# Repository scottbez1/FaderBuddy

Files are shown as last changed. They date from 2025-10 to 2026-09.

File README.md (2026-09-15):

# FaderBuddy

The FaderBuddy is a modular control board for 60mm motorized linear potentiometers, making it simple to add
one (or many) to a project with just 2 pins for I2C, plus power!

DSC_8984 Large

The control board allows you to **read** the fader position, **move** the fader to a specified position, and it can even provide **haptic feedback** and virtual detents (kind of like a linear version of my [SmartKnob](https://github.com/scottbez1/smartknob) project), all easily controlled over an I2C bus from a host controller like an ESP32.

An [ESPHome component](ABOUT_ESPHOME_INTEGRATION.md) allows
FaderBuddy assemblies to be seamlessly integrated into Home Assistant with just a few lines of yaml! 

The onboard ATtiny1616 microcontroller handles all the real-time logic (closed-loop motor control and capacitive
touch handling) and provides a simple I2C bus interface - no need to wire a motor driver/H-bridge or implement a PID control loop for each motor fader yourself.

Multiple FaderBuddy boards can be wired together and share just two I2C pins. With right-angle pin headers, you can plug adjacent FaderBuddy boards into
each other without any wires for an easy plug-and-play expandable system (supports 18mm or 19mm spacing between faders).
STEMMA QT/QWIIC-compatible connectors make it easy to hook FaderBuddy boards to the rest of your design (see [wiring diagrams](#wiring-overview) below for examples).

<!--
<img alt="motor fader demo tiny" height="427" src="https://github.com/user-attachments/assets/fc8dd191-fca0-4ac6-80d8-bb88dc9d0a7a" />
-->
<p align="center">
FaderBuddySimpleTopDown
</p>

The [FaderBuddy community Discord server](https://discord.gg/xZXQAp5cue) is the best place to keep up with the latest changes or ask questions about the project!

<p align="center">
<a href="https://www.youtube.com/shorts/l-DIM_kQ8EY" target="_blank">
thumbnailPlayButton
</a>
</p>

Learn more about the project and how to build your own below, or purchase a FaderBuddy from the [Bezek Labs Etsy store](https://bezeklabs.etsy.com/listing/4506790932/) (US-only).

---

Want to help support development or just say "thanks"? Consider a one-time or monthly sponsorship:

| [:heart: Sponsor scottbez1 on GitHub](https://github.com/sponsors/scottbez1) |
|---|

**Using this project in a commercial setting or for paid client work?** Go right ahead - it's open source (just make sure to follow the terms of the Apache License including attribution)! I would, however, ask that you consider [sponsoring the project](https://github.com/sponsors/scottbez1). Sponsorships allow me to pay for prototypes and development tools that make this project possible. Unlike pure software projects, every iteration has real hardware costs; sponsorships allow me to keep iterating and improving this and other projects faster. Thank you!

---

## ESPHome Integration

The FaderBuddy integrates seamlessly with [ESPHome](https://esphome.io/) for Home Assistant automation. The custom component provides:
- Bidirectional (input & output) position sync with Home Assistant entities
- Layer-aware automation triggers (manual_move, touch_change, double_tap)
- Per-layer haptic configuration
- Multiple faders on a single ESP32 via I2C

A simple example looks like:
```yaml
external_components:
  - source: github://scottbez1/FaderBuddy

fader_buddy:
  - id: my_fader
    on_manual_move:
      then:
        - lambda: |-
            ESP_LOGD("fader", "Fader moved to %d on layer %d", x, layer);
```

and to move the fader from a lambda:
```cpp
id(my_fader).remote_move_to(position, layer);

// optionally cap the speed - 0-255, where 255 is full speed
id(my_fader).remote_move_to(position, layer, 128);
```

That's pretty much all there is to it!

See [ABOUT_ESPHOME_INTEGRATION.md](ABOUT_ESPHOME_INTEGRATION.md) for setup instructions and many more examples.

## Getting Started
What you need:
- **60mm motorized fader**: Behringer MF60T faders (sold in 5-packs as replacement parts) from music/AV retailers like [Sweetwater](https://www.sweetwater.com/store/detail/MOTORFADER--behringer-mf60t-motorized-faders-set-of-5-for-motor-controllers) or [Amazon](https://www.amazon.com/Behringer-MOTOR-High-Performance-Faders-Keyboards/dp/B01DT827IC) - these appear to be manufactured by Soundwell
- **FaderBuddy PCB**: Available [pre-assembled from Bezek Labs](https://bezeklabs.etsy.com/listing/4506790932) in the US (purchasing there directly supports this project), or use the design files fabricate and assemble your own PCBs via JLCPCB. See [ABOUT_PCB_FABRICATION.md](ABOUT_PCB_FABRICATION.md) for details.
- **ESP32**: Any ESPHome-compatible ESP32 board with 2 free GPIO pins for I2C.

> [!NOTE]
> If fabricating your own boards via JLCPCB, you'll also need to flash the firmware before use. See [ABOUT_UPDATING_FIRMWARE.md](ABOUT_UPDATING_FIRMWARE.md) for instructions.

## Wiring Overview
| Pin | Details |
| --- | --- |
| Vmot | Motor power - 5v recommended |
| Vio | Microcontroller IO power - 3.3v or 5v. This must match the voltage for the SDA/SCL I2C bus! |
| GND | Ground reference |
| SDA | I2C data. FaderBuddy includes a pull-up resistor |
| SCL | I2C clock. FaderBuddy includes a pull-up resistor |

### 3.3v MCU direct wired, direct chaining
Most common wiring for 3.3v microcontrollers like ESP32: 5 wires from host to FaderBuddy. 5v powers the motor and 3.3v powers the logic.

FaderBuddy wiring

| HOST | FaderBuddy |
| --- | --- |
| 5v  | Vmot |
| 3.3v | Vio |
| GND | GND |
| SDA | SDA |
| SCL | SCL |

<br clear="right" />

### 3.3v MCU STEMMA QT
For a microcontroller with a STEMMA QT connector, the FaderBuddy requires an additional 5v wire to power the motor. Additional faders can be chained directly using the pin headers with no extra wires.

FaderBuddy wiring(2)

| HOST | FaderBuddy |
| --- | --- |
| STEMMA QT | STEMMA QT |
| 5v  | Vmot |

<br clear="right" />
<br />
FaderBuddy wiring(1)
Alternatively, FaderBuddy boards can be chained using STEMMA QT cables, but an additional 5v wire is also required between each board in that case.
<br clear="right" />

### 5v STEMMA QT
If you have a device that has 5v IO and a 5v STEMMA QT connector (e.g. MCP2221 with the solder jumper bridged to set 5v IO)

FaderBuddy wiring(4)

| HOST | FaderBuddy |
| --- | --- |
| STEMMA QT | STEMMA QT |

You must also bridge the V<sub>MOT</sub> ↔ V<sub>IO</sub> solder bridge on _each_ FaderBuddy so that the 5v IO can be shared with the motor driver.

_Be careful when using these solder bridges - if you leave this connection bridged and then later use the FaderBuddy in a 3.3v IO setting, the bridge will connect the 5v V<sub>MOT</sub> supply to your host 3.3v IO supply which may damage other connected devices!_

<br clear="right" />
(Board images attribution: ESP32-C3 supermini image from StudioPieters, MIT Licensed; Adafruit Qt Py and Adafruit MCP2221 images from Adafruit, Creative Commons Attribution/Share-Alike)

### Setting I2C Address
By default the FaderBuddy will use I2C address `0x20`.

When connecting more than one FaderBuddy to the same I2C bus, or if there's already another device on your bus with that address, the FaderBuddy PCB has 3 solder jumper pads allowing you to change the I2C address by bridging those pads.

| Address | A2 | A1 | A0 |
| --- | ----- | ----- | ----- |
| `0x20`  | `[ ]` | `[ ]` | `[ ]` |
| `0x21`  | `[ ]` | `[ ]` | `[█]` |
| `0x22`  | `[ ]` | `[█]` | `[ ]` |
| `0x23`  | `[ ]` | `[█]` | `[█]` |
| `0x24`  | `[█]` | `[ ]` | `[ ]` |
| `0x25`  | `[█]` | `[ ]` | `[█]` |
| `0x26`  | `[█]` | `[█]` | `[ ]` |
| `0x27`  | `[█]` | `[█]` | `[█]` |

## About the Board Design
The most plug-and-play option (if you're in the US) is to buy the FaderBuddy PCBs [pre-assembled from the Bezek Labs store](https://bezeklabs.etsy.com/listing/4506790932), which come with firmware already flashed, the hardware tested, and it helps support this project and future development!

To fabricate or assemble the PCBs yourself, see [ABOUT_PCB_FABRICATION.md](ABOUT_PCB_FABRICATION.md) for more info on ordering.

**Hardware details:**
- ATtiny1616 microcontroller with UPDI programming interface
- Supports 3.3v or 5v logic (with 3.3v logic, 5v is still required for powering the motor; with 5v logic Vio and Vmot can be combined for only 4 wires)
- DRV8837 motor driver, with potentiometer position feedback for closed-loop control
- JST connectors for I2C (QWIIC/STEMMA QT-compatible), or 0.1" pin headers for directly chaining adjacent boards
- Capacitive touch sensing for fader touch detection
- Power and debug status LEDs
- Compact PCB design optimized for JLCPCB assembly

<a href="https://motorfader-artifacts.s3.amazonaws.com/master/electronics/fader_buddy_main-schematic.pdf">
    
</a>
<br />
<a href="https://motorfader-artifacts.s3.amazonaws.com/master/electronics/fader_buddy_main-3D_top.png">
    
</a>
<a href="https://motorfader-artifacts.s3.amazonaws.com/master/electronics/fader_buddy_main-3D_bottom.png">
    
</a>

## Touch-compatible Fader Knobs/Caps
You don't _need_ touch capable fader caps - the FaderBuddy will work fine without them - but touch detection allows the FaderBuddy to cancel a motor movement if it detects a touch along the way, preventing the fader from "fighting" against the user. It also allows the FaderBuddy to detect if a user is touching the fader even if they aren't actively moving, and allows you to support a double-tap action on the fader if you'd like.

It's unfortunately nearly impossible to find off-the-shelf mass produced touch-capable fader knobs. Although the Soundwell/Behringer faders use a relatively standard 8mm x 1.2mm fader stem, pretty much all commercially available fader caps are non-conductive plastic and thus do not support touch detection, or are only available as expensive individual replacement parts (oftentimes in used condition).

However, I've found that you can 3D print touch-capable fader caps using conductive PLA filament. Although conductive PLA is generally very high resistance, this is actually a great property for making a touch detection surface.

If you don't want to print your own, you can purchase these 2-color single-piece conductive fader caps in the [Bezek Labs store](https://bezeklabs.etsy.com/listing/4501804398).

<a href="https://bezeklabs.etsy.com/listing/4501804398">
Screenshot 2026-05-15 at 9 19 08 AM
Screenshot 2026-05-15 at 9 19 33 AM
<br />
Screenshot 2026-05-15 at 9 19 56 AM
</a>

## Firmware, I2C interface, and Layers
The FaderBuddy firmware internally handles the closed loop motor control, presenting a [simple I2C interface](firmware/src/shared/i2c_data.h) that can be used to read the position and status of the board, command a movement to a position, and configure haptic feedback. This I2C interface is wrapped up in the ESPHome component, making it a great reference for how to interact with the protocol if you'd like to connect your FaderBuddy to something besides an ESP32 with ESPHome.

- Programmable haptic-feedback modes:
  - Smooth operation (no detents)
  - Magnetic endpoints (snap to 0% and 100%)
  - Configurable detents (1-15 positions)

Configuration of a FaderBuddy supports up to 8 virtual "layers", which allow a single fader to be used for multiple purposes (e.g. controlling lamp brightness and fan speed), with the host controller able
to send a single command to switch to a different layer. Switching layers restores the previous
fader position for that layer, and will apply that layer's haptic configuration.

See [ABOUT_LAYERS.md](ABOUT_LAYERS.md) for more about layers and the I2C protocol.

## Additional Documentation
This README covers the basics, but there are a number of additional pages with more detailed documentation:

- **[ABOUT_ESPHOME_INTEGRATION.md](ABOUT_ESPHOME_INTEGRATION.md)** - ESPHome setup and API reference
- **[ABOUT_LAYERS.md](ABOUT_LAYERS.md)** - Layer architecture and implementation details
- **[ABOUT_MF60T_LOW_PROFILE_MOD.md](ABOUT_MF60T_LOW_PROFILE_MOD.md)** - Optional instructions for modifying the MF60T faders so they can fit in smaller areas
- **[ABOUT_PCB_FABRICATION.md](ABOUT_PCB_FABRICATION.md)** - How to order and assemble your own FaderBuddy boards directly
- **[ABOUT_UPDATING_FIRMWARE.md](ABOUT_UPDATING_FIRMWARE.md)** - How to upload firmware to the FaderBuddy microcontroller using UPDI
- **[ABOUT_I2C_BOOTLOADER.md](ABOUT_I2C_BOOTLOADER.md)** - How firmware updates work over I2C (no UPDI programmer), via the custom bootloader in the ATtiny1616 boot section

### Project Structure
```
FaderBuddy/
├── electronics/         # KiCad PCB design files
├── firmware/            # ATtiny1616 firmware source (PlatformIO)
├── esphome/             # ESPHome custom component
│   ├── components/      # Component source code
│   └── examples/        # Example configurations
├── software/            # Software tools and demos
│   └── mcp2221-webhid/  # WebHID browser demo tool
├── production_tools/    # ESP32-based production test fixture
└── ci/                  # CI scripts for PCB export
```

## Production Testing

The `production_tools/programAndTest` directory contains unsupported (source-provided) code for programming and quality control of motor fader boards during production.

## License

FaderBuddy is released under the [Apache 2.0 License](LICENSE.txt).

In plain terms: you're free to use, modify, and distribute this project — including in commercial products — as long as you include the license with attribution to this project and indicate any changes you made. You don't have to share your modifications, but you can't claim the original work is yours or use the project name/branding to endorse your product.

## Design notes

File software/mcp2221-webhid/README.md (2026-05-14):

# FaderBuddy WebHID Demo

Web-based interface for controlling FaderBuddy devices via MCP2221 USB-to-I2C bridge using WebHID.

## Setup

1. Install dependencies:
```bash
npm install
```

2. Build the bundle:
```bash
npm run build
```

3. Open `index.html` in a WebHID-compatible browser (Chrome, Edge, or other Chromium-based browsers)

## Development

To automatically rebuild on file changes:
```bash
npm run watch
```

## Usage

1. Connect your MCP2221 USB device to your computer
2. Ensure the FaderBuddy is connected to the MCP2221's I2C pins
3. Open `index.html` in your browser
4. Click "Connect MCP2221" and select the device
5. Verify the I2C address matches your fader (default: 0x20)
6. Control and monitor your FaderBuddy in real-time

## Features

- Real-time position monitoring (10Hz polling)
- Bidirectional control (set target position)
- Mode state visualization
- Touch detection monitoring
- Touch diagnostics (raw/delta/reference values)
- Error handling and recovery
- Self-calibration trigger

## Requirements

- WebHID-compatible browser (Chrome 89+, Edge 89+)
- MCP2221/MCP2221A USB-to-I2C bridge
- FaderBuddy hardware with I2C interface

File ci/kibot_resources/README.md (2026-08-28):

# KiBot resources

KiBot's `resources_dir` global option (set in the `.kibot.yml` files) points here.
At startup KiBot globs `<resources_dir>/fonts/*.ttf` and installs what it finds
into `~/.fonts` *inside its Docker container* — that's the only way KiCad running
under the KiBot Actions can see a custom font, since it can't read the fonts that
`ci/electronics/dependencies.sh` installs on the runner itself.

The glob is flat and non-recursive, so the font has to sit directly in `fonts/`.
`fonts/Righteous-Regular.ttf` is therefore a symlink to the real file in
`ci/fonts/Righteous/`, which is where the runner-side tooling reads it from.

Symptom if this breaks: silkscreen text that uses the Righteous outline font
renders in KiCad's default stroke font in the 3D renders, while the gerbers (which
are plotted on the runner, not in the container) still look correct.

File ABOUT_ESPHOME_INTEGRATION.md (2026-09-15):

# FaderBuddy ESPHome Integration

This guide shows you how to use the FaderBuddy with ESPHome to create smart motorized controls for Home Assistant or other home automation systems.

## Hardware Setup

### Wiring

Connect your FaderBuddy board(s) to your ESP32 via I2C:

- **SDA** → ESP32 GPIO pin (e.g., GPIO8)
- **SCL** → ESP32 GPIO pin (e.g., GPIO9)
- **GND** → ESP32 GND
- **Vio** → 3.3V power supply
- **Vmot** → 5V power supply

**I2C Addressing**: Each FaderBuddy has a configurable I2C address (default 0x20, configurable via hardware jumpers to 0x20-0x27). When using multiple faders on the same I2C bus, ensure each has a unique address.

### I2C Bus Configuration

In your ESPHome YAML, configure the I2C bus:

```yaml
i2c:
  sda: GPIO8
  scl: GPIO9
  scan: true  # Optional: helps verify faders are detected
```

## Adding the Component

### External Component Reference

Add the fader_buddy component to your ESPHome configuration using the GitHub repository:

```yaml
external_components:
  - source:
      type: git
      url: https://github.com/scottbez1/FaderBuddy.git
      ref: master  # or specify a specific tag/branch
    components: [fader_buddy]
```

## Basic Configuration

### Single Fader Setup

Here's a minimal configuration for one FaderBuddy:

```yaml
fader_buddy:
  - id: my_fader
    address: 0x20          # I2C address (default 0x20)
    update_interval: 10ms  # How often to poll the fader
```

### Multiple Faders

To use multiple faders, add multiple entries with unique IDs and addresses:

```yaml
fader_buddy:
  - id: fader_1
    address: 0x20
    update_interval: 10ms

  - id: fader_2
    address: 0x21
    update_interval: 10ms

  - id: fader_3
    address: 0x22
    update_interval: 10ms
```

## Complete Example: Light Brightness Control

This example shows bidirectional control - a single fader controlling a Home Assistant light's brightness and responding to remote changes to that light's brightness:

```yaml
fader_buddy:
  - id: brightness_fader
    address: 0x20
    update_interval: 10ms
    layer_haptics:
      - layer: 0
        mode: smooth
        default_speed: 120  # move deliberately rather than instantly

    # User moves fader → update light brightness
    on_manual_move:
      then:
        - homeassistant.action:
            action: light.turn_on
            data:
              entity_id: light.living_room
              brightness: !lambda 'return x;'
              transition: "0"

# Light brightness changes in Home Assistant → move fader
sensor:
  - platform: homeassistant
    id: living_room_brightness
    entity_id: light.living_room
    attribute: brightness
    internal: true
    on_value:
      then:
        - lambda: |-
            id(brightness_fader).remote_move_to(isnan(x) ? 0 : x);
```

For additional complete working examples, see the `esphome/examples/` directory:

- **multi-fader-display.yaml** - Three faders with an LVGL display, showing haptic configuration, layer setup, and Home Assistant integration

## Configuration Options

### Component Configuration

- **id** (required): Unique identifier for this fader instance, used to reference it in automations and lambdas
- **address** (optional, default: `0x20`): I2C address of the fader (0x20-0x27)
- **update_interval** (optional, default: `50ms`): How often to poll the fader for state updates
- **invert** (optional, default: `false`): Reverse the fader direction (position 0 becomes 255, and vice versa)
- **layer_haptics** (optional): List of haptic configurations for specific layers. See `ABOUT_LAYERS.md` for more details on layers
  - **layer** (required): Layer index (0-7) for this list item
  - **mode** (required): Haptic mode - one of:
    - `smooth`: No haptic feedback, completely smooth movement
    - `smooth_with_magnets`: Smooth with magnetic endpoints that pull the fader to min/max
    - `detents`: Creates distinct "notches" along the fader's travel (requires `detent_count`)
  - **detent_count** (optional, default: `0`): Number of detents (1-15, for detents mode only)
  - **detent_strength** (optional, default: `0`): Detent force feedback strength (0-7, for detents mode only)
  - **default_speed** (optional, default: `255`, requires fader firmware 1.1+): Move speed for this layer, 0-255, used by `fader_buddy.remote_move_to` and by lambda calls to `remote_move_to()` that don't pass a speed of their own. `255` is full speed; see the `speed` parameter of `fader_buddy.remote_move_to` below. This one is tracked in ESPHome rather than on the fader — the component looks up the active layer's value and sends it with each move — so changing it costs no extra I2C traffic.
  - **value_change_min_interval** (optional, default: `0ms`): Rate limiting for `on_manual_move` trigger on this layer. Useful to reduce traffic when controlling networked devices like zigbee lights. Set to `0ms` for no rate limiting. Keep as low as possible.
- **firmware** (optional): Released fader firmware to package for I2C updates. See [Firmware updates](#firmware-updates) below. Mutually exclusive with `firmware_image`.
- **firmware_image** (optional): Path to a locally built application image, for iterating on an unreleased build. Mutually exclusive with `firmware`.

### Triggers

The component provides four triggers that fire in response to fader state changes:

#### on_manual_move

Fires when the user moves the fader. Only fires during `MODE_INPUT_ACTIVE` or `MODE_INPUT_IDLE` (i.e. not during remote motor movements). Respects `value_change_min_interval` rate limiting configured in `layer_haptics`. Provides the current position (0-255) and active layer index.

```yaml
fader_buddy:
  - id: my_fader
    on_manual_move:
      then:
        - lambda: |-
            // x = position (0-255)
            // layer = active layer (0-7)
            ESP_LOGD("fader", "Fader moved to %d on layer %d", x, layer);
```

#### on_touch_change

Fires when the user touches or releases the fader. Provides touch state (true/false) and active layer index.

```yaml
fader_buddy:
  - id: my_fader
    on_touch_change:
      then:
        - lambda: |-
            // x = touch state (true/false)
            // layer = active layer (0-7)
            ESP_LOGD("fader", "Touch: %s (on layer %d)", x ? "pressed" : "released", layer);
```

#### on_double_tap

Fires when the user double-taps the fader. Provides the active layer index.

```yaml
fader_buddy:
  - id: my_fader
    on_double_tap:
      then:
        - lambda: |-
            // layer = active layer (0-7)
            ESP_LOGD("fader", "Double tap on layer %d", layer);
```

#### on_raw_position_update

_Not recommended for general use!_ Fires on every position change detected by the hardware, regardless of the current mode and without any rate limiting. This includes position changes during remote motor movements (`MODE_REMOTE_MOVEMENT_IN_PROGRESS`), not just user-initiated moves. Provides the current position (0-255, after applying `invert`) and active layer index.

For most use cases, prefer `on_manual_move`. Use `on_raw_position_update` only when you specifically need to track the fader's physical position at all times — for example, to update a display that should reflect position even while the motor is actively moving.

```yaml
fader_buddy:
  - id: my_fader
    on_raw_position_update:
      then:
        - lambda: |-
            // x = position (0-255)
            // layer = active layer (0-7)
            ESP_LOGD("fader", "Raw position: %d on layer %d", x, layer);
```
## Actions

### fader_buddy.remote_move_to

Command the fader to move to a specific position.

```yaml
# Example: Move fader to position 128
- fader_buddy.remote_move_to:
    id: my_fader
    position: 128
    layer: 0  # Optional, defaults to layer 0

# Example: move gently rather than at full speed
- fader_buddy.remote_move_to:
    id: my_fader
    position: 200
    speed: 80
```

**Position:** 0-255 (0 = bottom, 255 = top, unless inverted)

**Layer:** Optional layer index (0-7). If the specified layer is not currently active, the position is stored and will be restored when that layer becomes active.

**speed:** Optional. How fast to move, as a unitless **0-255** value: `255` is full speed, `0` is the slowest the fader moves smoothly. Omit it to use the layer's `default_speed`.

Requires fader firmware **1.1 or newer**. On older firmware the component logs a warning once and moves at full speed instead; it checks the firmware version at startup, so a `default_speed` that cannot be honoured is reported then rather than on the first move.

The scale is linear in velocity, and both ends are usable — `0` is the slowest speed the mechanism sustains without creeping in stick-slip steps (roughly 700ms for full travel), and `255` removes the limit entirely. There is nothing outside the range worth reaching for.

This caps the fader's speed rather than scheduling the move, so a shorter move takes proportionally less time — at a given speed, a half-scale move takes about half as long as a full-scale one. Slowing moves down is mostly useful when several faders move at once, or when you want motion to read as deliberate rather than instant.

Treat it as a limit rather than a precise speed. It is realised through a friction-dependent mechanism, so actual velocity lands within about 15% of nominal, with around 7% difference between moving up and moving down.

Moving a layer that is not currently active also stores the speed, so it applies when that layer is restored later.

### fader_buddy.set_active_layer

Switch to a different layer (0-7). The fader will automatically move to that layer's last position.

```yaml
# Example: Button to switch to layer 1
binary_sensor:
  - platform: gpio
    pin: GPIO4
    on_press:
      - fader_buddy.set_active_layer:
          id: my_fader
          layer: 1
```

### fader_buddy.set_layer_haptic_config

Dynamically change the haptic configuration for a layer.

```yaml
# Example: Set layer 2 to detents mode with 10 detents
- fader_buddy.set_layer_haptic_config:
    id: my_fader
    layer: 2
    mode: detents
    detent_count: 10
    detent_strength: 5
```

### fader_buddy.run_self_calibration

Trigger the fader's self-calibration routine. The fader will automatically move to both endpoints to calibrate its potentiometer range.

```yaml
# Example: Calibration button
button:
  - platform: template
    name: "Calibrate Fader"
    on_press:
      - fader_buddy.run_self_calibration:
          id: my_fader
```

## Firmware updates

The fader's own ATtiny1616 firmware can be updated over I2C through its bootloader,
without a UPDI programmer. The image is embedded in the ESP32 build and streamed to
the fader when you call `fader_buddy.update_firmware`.

### Referencing a released image

Application images are published as assets on a GitHub release, tagged
`releases/firmware/v<major>.<minor>` — the same tag scheme the electronics artifacts
use. Naming the version is enough; the download URL follows from it:

```yaml
fader_buddy:
  - id: my_fader
    firmware: "1.3"
```

The image is downloaded at **compile time**, verified against the `sha256` recorded
in `KNOWN_FIRMWARE` (in `esphome/components/fader_buddy/__init__.py`), cached by
hash, and compiled into the ESP32 binary. Nothing is fetched at runtime.

The hash is the point: it pins the exact bytes, so a re-uploaded or substituted
release asset fails the build rather than being flashed onto a fader. A version with
no `KNOWN_FIRMWARE` entry is an error unless you supply the hash yourself:

```yaml
    firmware:
      version: "1.3"
      url: https://example.com/fader_buddy_app_v1.3.bin   # optional, defaults to the release asset
      sha256: 2d2e56fa...                                  # required if not in KNOWN_FIRMWARE
```

Two things are checked at config time, so problems surface from `esphome config`
rather than partway through a compile or — worse — on the fader:

- the image is the expected size and page-aligned, i.e. actually an app image and
  not a truncated download or an Intel-hex;
- the `FW_VERSION` baked into the image's last two bytes matches the version you
  asked for, catching a mislabelled or wrongly attached release asset.

### Using a locally built image

For firmware you haven't released yet, build and point at the file directly:

```bash
source ~/.platformio/penv/bin/activate
python3 firmware/tools/export_app_image.py --output fader_app.bin
```

```yaml
fader_buddy:
  - id: my_fader
    firmware_image: fader_app.bin
```

The binaries are **not** checked into the repository — they are build artifacts,
reproducible from any tagged commit.

### Triggering an update

A fader with `firmware:` or `firmware_image:` configured gets a **Firmware
Update** button automatically, so there is nothing to write for the common case —
it shows up in Home Assistant under the device's settings
(`entity_category: config`). Without a configured image there is nothing to
install, so no button is created. Rename or hide it on the hub:

```yaml
fader_buddy:
  - id: my_fader
    firmware: "1.3"
    firmware_update:
      name: "Update Fader Firmware"
      # internal: true          # to keep it out of Home Assistant entirely
```

A press is ignored unless there is genuinely something to install — a fader
already running the packaged version, or firmware too old to reach its
bootloader, just logs a line and does nothing, rather than tying up the I2C bus
for tens of seconds to reach the same answer. That check happens at press time
because whether an update is pending is runtime state rather than something the
yaml knows.

The equivalent action, for driving an update from an automation:

```yaml
button:
  - platform: template
    name: "Update Fader Firmware"
    on_press:
      - fader_buddy.update_firmware:
          id: my_fader
```

Updates only ever happen when the button is pressed or the action runs — there is
no automatic update mode. The component refuses to start if the fader is being
touched, if the target version is already installed, or if the fader's firmware
predates I2C bootloader entry (`FW_VERSION` below 1.3), which needs a one-time
UPDI migration. A failed update is not retried on its own and not counted
anywhere: press the button again.

The action **returns immediately** — the transfer then runs a slice at a time from
the main loop, so the device stays responsive throughout. The outcome arrives on
`on_firmware_update_result`, not when the action returns.

### Watching an update

The **Firmware Version** text sensor doubles as the update's status field — a fader
mid-update has no version to report, so it says what it is doing instead:
`waiting for fader` → `entering bootloader` → `erasing` → `writing 25%` … →
`verifying` → `starting app`, then the new version (e.g. `1.5`). A failed update
ends on the fader's real state with the reason appended, e.g. `1.3 (update failed)`
or `bootloader (no app) (update failed)` if it was stranded mid-write. A fader that
is sitting in its bootloader at startup reads `bootloader (no app)` from the outset.

How much of the progress Home Assistant actually renders depends on `api:
batch_delay:`. Entity states are batched and deduplicated per entity, so at the
default 100ms HA sees the steps that happen to straddle a flush rather than all of
them. Set `batch_delay: 0ms` to see each one. The ESPHome log always shows every
step, and the terminal states always get through either way.

The serial number sensor is re-read after a successful update too — a fader that
booted into its bootloader could never report one, since `REG_SERIAL` is an app
register.

One case is updatable even though no version can be read: a fader sitting in its
bootloader with no working app image (see the forced-entry strap in
`ABOUT_I2C_BOOTLOADER.md`). The component notices that at startup, logs it, and
keeps the button live so the fader can be recovered.

### Cutting a release

```bash
git tag releases/firmware/v1.3 && git push origin releases/firmware/v1.3
```

CI builds the image, refuses to publish if the tag and the firmware's own
`FW_VERSION` disagree, attaches `fader_buddy_app_v1.3.bin` to the release, and
prints the `KNOWN_FIRMWARE` line to paste into the component.

## Text Sensors

### serial_number

You can expose the microcontroller's serial number as a text sensor, which is handy for identifying a specific board for diagnostics. The serial is read once at startup and published as an uppercase hex string.

```yaml
text_sensor:
  - platform: fader_buddy
    fader_buddy_id: my_fader
    serial_number:
      name: "Fader Serial Number"
```

The `serial_number` block accepts the standard ESPHome text sensor options (e.g. `name`, `id`, `icon`). It defaults to the `diagnostic` entity category.

## C++ API (for Lambdas)

When writing lambda expressions, you can call these methods directly on the component:

```cpp
// Layer management
id(my_fader).set_active_layer(layer_index);       // Switch to layer 0-7
uint8_t layer = id(my_fader).get_active_layer();  // Get current active layer

// Position control
id(my_fader).remote_move_to(position, layer);     // Move on specific layer
uint8_t pos = id(my_fader).get_position(layer);   // Get position for layer

// Haptic configuration
id(my_fader).set_layer_haptic_config(layer, mode, detent_count, detent_strength);

// Calibration
id(my_fader).run_self_calibration();

// Serial number (empty until read at startup)
std::string serial = id(my_fader).get_serial_number();
```

## Troubleshooting

**Fader not detected:**
- Check I2C wiring (SDA, SCL, GND, Vio, Vmot)
- Verify I2C address matches your hardware configuration
- Enable `scan: true` in the I2C config to see detected addresses in logs
- Two faders strapped to the same address look like this on a chain: the
  duplicated address returns garbage, and the address nobody is using goes
  silent. The boot scan is the quickest way to rule it out - count the
  addresses, not the faders

**A fader's serial number and firmware version both read Unknown:**

Both sensors are published during initialization, which only runs once the
fader answers a probe of `REG_VERSION`, so Unknown means that probe never got a
usable answer. The boot log says which of the two cases it was:

- `Init: no response from the fader at 0xNN after 5 attempts` - it NAKed, or
  isn't there. With a `firmware:`/`firmware_image:` configured, the component
  stays alive and re-probes on a doubling backoff — at roughly 1, 3, 7, 15 and
  31 seconds after boot — so a fader that turns up late initializes itself.
  After that it is left alone rather than tying up the bus on every poll. The
  firmware version sensor reads `not responding`, and the **Firmware Update**
  button stays pressable in case the fader is wedged rather than absent;
  pressing it is also how to retry once the backoff has run out. With no image configured there is
  nothing to recover with, so the component is marked failed until reboot.
- `Init: Incompatible I2C protocol version ... got N` - it answered, with a
  protocol older than v5. That firmware also predates I2C bootloader entry
  (firmware 1.3), so it needs a one-time UPDI reflash; no update over I2C can
  reach it. The component is marked failed.

A fader sitting in its bootloader with no application is *neither* of these -
it answers the probe with its own marker, reports `bootloader (no app)` as its
firmware version, and is recovered by pressing **Firmware Update**.

**Fader moves in wrong direction:**
- Set `invert: true` in the component configuration

**Trigger fires too frequently or sporadic movement in a bidirectional setup:**
- Use `value_change_min_interval` in `layer_haptics` to rate limit
- Example: `value_change_min_interval: 100ms` limits to 10 updates per second
- This can be useful if you have a bidirectional setup (i.e. moving the fader controls a light in HASS, and changing a light in HASS moves the fader) and the on_manual_move trigger takes a while to be confirmed/reflected, for example when updating a high-roundtrip-latency light like a Zigbee light. Without rate-limiting, this can often result in weird motor movements after manually moving the fader, as HASS may queue up brightness changes that happen too quickly and then deliver them for while after you've already let go, causing the motor to almost replay your previous movement.

**Fader doesn't move to commanded position:**
- Run self-calibration: `fader_buddy.run_self_calibration`
- Check that you're not in an error state (power cycle if needed)

## Additional Resources

- **Layer Architecture:** See `ABOUT_LAYERS.md` for detailed information about the layer system
- **I2C Protocol:** See `firmware/src/shared/i2c_data.h` for low-level protocol details
- **Example Configurations:** See `esphome/examples/` directory

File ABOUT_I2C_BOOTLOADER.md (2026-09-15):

# I2C Bootloader (ATtiny1616)

FaderBuddy firmware can be updated over the I2C bus, with no UPDI programmer
attached. A small bootloader lives in the ATtiny1616's hardware boot section and
writes the application section on command from the host.

This document describes how that works, what it guarantees, and where it is
still weak. Commands for building, flashing and testing live in
[CLAUDE.md](CLAUDE.md).

## 1. Goal and constraints

Without the bootloader, an ATtiny1616 can only be flashed with a physical UPDI
programmer on three test pads (see
[ABOUT_UPDATING_FIRMWARE.md](ABOUT_UPDATING_FIRMWARE.md)). The bootloader lets an
ESP32 host push updates over the wires that are already there. The design had to
work under four hard constraints:

- **No pin changes and no new wires.** Host and target share only I2C
  (SDA/SCL on the TWI0 pins).
- **The host cannot control target power.** Anything that needs a power cycle to
  enter update mode is out.
- **Keep the PlatformIO + megaTinyCore toolchain** for the ATtiny firmware.
- **A bad application must never brick a board.** Recovery has to stay possible
  over I2C.

The boot section satisfies all four. It owns the reset vector, so it always runs
first. NVMCTRL self-programming lets it write the application. Hardware write
protection stops the application from damaging it.

The one-time cost is a **single UPDI flash per board**, installing the
bootloader, the boot-section fuses, and an application linked at the post-boot
offset. After that, updates are I2C-only. UPDI stays the bring-up path for blank
chips and the recovery path of last resort.

## 2. Flash memory map

The ATtiny1616 has 16 KB of flash with a 64-byte page size (256 pages), mapped
into the data space at `FLASHSTART = 0x8000`. Two fuses split it into sections:

```
program view   data-space (mapped) view
0x0000         0x8000  ┌────────────────────────┐  ← reset vector (PC = 0x0000)
                       │  BOOT section          │     (always executes first on reset)
                       │  = the I2C bootloader  │
BOOTEND*256    0x8000+BOOTEND*256 ├──────────────┤  ← interrupt vectors + application start
                       │  APPCODE section       │
                       │  = the FaderBuddy app  │
0x4000         0xBFFF  └────────────────────────┘  (16 KB)
```

Two address spaces matter for the flash-write code. The program counter and the
section fuses use offsets from `0x0000`. Loads and stores that fill the page
buffer use the mapped view at `0x8000 + offset`. Everywhere below, "flash
address X" means the program/section offset; the store target is `0x8000 + X`.

- **`BOOTEND`** sets the boot-section size in 256-byte units. It is **`0x06`**
  (1536 bytes) today. The bootloader measures about 1366 bytes, leaving roughly
  170 bytes free.
- **`APPEND`** is `0x00`, so the application section runs to the end of flash.
  There is no separate APPDATA region.
- The application is linked to start at `BOOTEND * 256` = `0x0600`.

`BOOTEND` is not a value to change casually. Six places move in lockstep; the
comment on `BL_BOOTEND` in `firmware/src/shared/bootloader_protocol.h` lists
them.

Application flash is tight. The app has roughly 130 bytes of headroom below the
`.fw_meta` footer, and about 1.1 KB of the image is avr-libc soft-float pulled
in by the float-based control law in `motor_control.h`. Converting the control
hot path to fixed point is the next real source of app flash.

## 3. Boot-section integrity

Per the datasheet (*NVMCTRL — Memory Organization*, §9.3.1.1):

- **The CPU can never write the BOOT section.** This is inherent hardware
  behaviour, independent of any fuse or lock bit. Neither the application nor
  the bootloader itself can rewrite it.
- **Inter-section writes are directional.** BOOT code may write APPCODE and
  APPDATA. APPCODE may write only APPDATA. APPDATA may write neither.
- **`BOOTLOCK` and `APCWP`** are optional `NVMCTRL.CTRLB` lock bits, not fuses,
  and this design sets neither. `BOOTLOCK` also blocks reads and execution of
  the boot section, so setting it would stop the bootloader from running at all.

The consequence is the safety property the whole design rests on: **a buggy or
half-written application can never corrupt the bootloader.** Since the
bootloader runs first on every reset, even a completely broken application still
leaves a route back over I2C. As defence in depth, the bootloader also
bounds-checks every target page address in software.

The flip side is that **the bootloader itself is not field-updatable**. Changing
it always requires UPDI. Keeping it small and stable is therefore a feature, and
any change to it must stay compatible with hosts and application images already
in the field.

## 4. Interrupt vectors

`CPUINT.CTRLA.IVSEL` selects where the interrupt vector table is fetched from.
`IVSEL = 0`, the reset default, points at the start of the application section;
`IVSEL = 1` points at the boot section.

No code touches `IVSEL`. The bootloader uses no interrupts, so it does not care.
The application wants its vectors at the application start, which is exactly
what the reset default gives it, as long as it is linked with its vector table
at `BOOTEND * 256`. Reset always vectors to `0x0000` regardless of `IVSEL`.

## 5. Self-programming via NVMCTRL

Writing flash is a two-step "fill the page buffer, then issue a command" flow.
Per 64-byte page:

1. **Pre-check.** Poll `NVMCTRL.STATUS` until `FBUSY` and `EEBUSY` are clear.
2. **Clear the page buffer** with `NVMCTRL.CTRLA = PBC`. The buffer auto-clears
   after any reset, write, erase, or sleep-wake, so this is cheap insurance
   rather than a requirement.
3. **Fill the buffer** with ordinary stores to the mapped addresses
   (`0x8000 + offset`) of the target page. Stores to `0x0000`-based addresses
   would not reach flash.
4. **Erase and write** with `NVMCTRL.CTRLA = ERWP`.
5. **Check `WRERROR`** afterwards. No explicit wait is needed: the CPU is halted
   for the duration of the flash operation, so the next instruction does not run
   until it completes.

Every write to `NVMCTRL.CTRLA` goes through Configuration Change Protection,
using the **SPM** key `0x9D` (`_PROTECTED_WRITE_SPM`). The IOREG key `0xD8`
(`_PROTECTED_WRITE`) is for protected I/O registers such as `RSTCTRL.SWRR`, and
does not work for `NVMCTRL.CTRLA`.

Command values, from the datasheet `CTRLA.CMD` table (§9.5.1):

| Value | Name | Meaning | Notes |
|:-----:|---|---|---|
| 0x00  | — | No command | |
| 0x01  | `WP` | Write page | |
| 0x02  | `ER` | Erase page | |
| 0x03  | `ERWP` | Erase and write page | what page streaming uses |
| 0x04  | `PBC`  | Page buffer clear | |
| 0x05  | `CHER` | Chip erase (Flash + EEPROM) | **not used** — it would erase EEPROM too, losing calibration |

Because `BOOTEND` counts 256-byte units and 256 is a multiple of the 64-byte
page, the application start is always page-aligned. There is no partial-page
case at the section boundary.

## 6. Wire protocol

The bootloader drives the **TWI0** slave registers directly, polled, with no
ISR and no `Wire` library. That keeps it small and self-contained in the boot
section. The protocol is defined in
[`firmware/src/shared/bootloader_protocol.h`](firmware/src/shared/bootloader_protocol.h),
which is shared with every host.

**Address.** The bootloader answers on the **same address as the application** —
base `0x20` plus the 3-bit hardware address from PC2/PC1/PC0. A fader keeps its
identity in bootloader mode.

**Commands** (multi-byte fields big-endian, matching `i2c_data.h`):

| Opcode | Command | Payload / behaviour |
|:---:|---|---|
| `0x01` | `SET_PAGE_ADDR` | 2-byte flash page address; resets the frame counter and page buffer |
| `0x02` | `SEND_FRAME` | 16 data bytes + CRC16; 4 frames fill a 64-byte page, which then auto-writes |
| `0x03` | `RUN_APP` | leave bootloader mode and start the application |
| `0x04` | `ERASE_APP` | invalidate the application (see below) |
| `0x05` | `GET_STATUS` | read back `[version, status, last_error]` |
| `0x06` | `GET_VERSION_CRC16` | address + length → bootloader version + CRC16 of that flash range |

Master-write commands are processed at the **Stop** condition. Master-read
commands are processed at the address match. Reading register `0x00` returns
`BL_VERSION_MARKER` (`0xB0`), which is how a host tells bootloader mode from a
running application (see [§8](#8-version-identity-and-no-app-detection)).

**`ERASE_APP` erases only the first page**, the one holding the reset vector.
That is enough to mark the application invalid, and each streamed page is
written with `ERWP`, which erases it in place anyway. See
[§12](#12-implementation-notes) for why a full-section erase is avoided.

**The update sequence** is:

1. `ERASE_APP`
2. For each page: `SET_PAGE_ADDR`, then `SEND_FRAME` × 4
3. `GET_VERSION_CRC16` over the whole application region, to verify the write
4. `RUN_APP`

Per-frame CRC16 catches transfer errors as they happen. The whole-image CRC
catches anything missed and stops the host from jumping into a bad image.

## 7. Entering the bootloader

There is no power-cycle control, so entry is application-triggered, with a
hardware escape hatch for when the application cannot help.

### From a running application

1. The host writes `REG_ENTER_BOOTLOADER` (0x10) with the magic payload
   `ENTER_BOOTLOADER_MAGIC`. The magic means a stray or corrupt write cannot
   reboot a fader by accident.
2. The I2C ISR only sets a flag. The main loop then writes the **entry token**
   and issues a software reset via `RSTCTRL.SWRR`.
3. The bootloader runs, reads `RSTCTRL.RSTFR` to confirm the reset was a
   software reset (`SWRF`), and checks the token. If both match it stays
   resident. Otherwise it clears the token and starts the application. Either
   way it writes `RSTFR` back to clear the sticky flags.

The entry token is a `.noinit` RAM variable pinned to **`0x3F00`** in both
builds. RAM survives a warm reset, and the C runtime does not clear `.noinit`.
GPIOR registers cannot be used for this: they are cleared by every reset,
including a software reset.

Requiring both the reset-cause flag and the token makes accidental entry
effectively impossible. After a power-on reset, RAM is indeterminate, but that
path has neither `SWRF` set nor a valid token, so it correctly falls through to
the application.

### Forced entry with the TP5 strap

`REG_ENTER_BOOTLOADER` only works if the application runs and answers the bus.
Two failure modes escape it: an image that was partially written but whose reset
vector happens to be programmed, so `app_is_valid()` accepts it; and an
application that starts but wedges before serving I2C. Both leave a fader
looking dead.

**TP5 (PB5)** is the hardware escape. Its net is the MCU pin and one test pad on
the back of the board, and nothing else, so only a deliberate short pulls it
low. To use it:

1. Short TP5 to any ground. The nearest are R2 and J4, about 4 mm away.
2. Power-cycle or reset the board.
3. Release the short. It only has to be held across reset.

The bootloader is then resident and answers `BL_VERSION_MARKER` at register
`0x00`. Update it normally, then send `RUN_APP`.

`strap_requests_bootloader()` enables the internal pull-up, samples the pin
eight times over a few hundred microseconds, and requires every sample to read
low. It then switches the pull-up back off, so the application sees the pin in
its reset state and a permanently grounded pad draws no current. The check costs
62 bytes of boot section and well under a millisecond on every boot.

For anyone revisiting the pin choice: PA3 (TP6) is TCA0 `WO3`, and PA4/PA5 are
`WO4`/`WO5`, the motor outputs, under this part's default `PORTMUX.CTRLC`
mapping. PA7 (TP1) and PB4 (TP4) are the equivalent alternatives. PB5 was taken
because the bootloader already drives PORTB for the heartbeat LED. TP2 and TP3
are RX/TX and are left for serial debug.

## 8. Version identity and "no app" detection

A host needs to tell three states apart on the bus, and needs a version to
compare against when deciding whether to update.

Reading register `0x00` is the universal probe:

| Response at `0x00` | Meaning |
|---|---|
| A valid protocol version (≥5) | The application is running normally |
| `0xB0` (`BL_VERSION_MARKER`)  | The bootloader is resident; no usable app |
| NAK / no response | Device absent, unpowered, or bus wedged |

`REG_VERSION` is a protocol compatibility version and is too coarse to drive
updates, so the application also serves **`REG_FW_VERSION`** (0x11), a packed
`(major << 8) | minor`. The host compares that against the version it has
packaged.

A board ends up bootloader-only in one of two ways: a bootloader flashed without
an application, or an update interrupted partway through. There is no atomic A/B
image — 16 KB of flash cannot hold two — so an update is not transactional. On
every boot the bootloader therefore runs `app_is_valid()`, which today checks
that the application's reset vector is not blank. If the check fails, the
bootloader stays resident and keeps answering with the marker, which is exactly
the state the host detects. That check is weaker than it should be; see
[§11](#11-known-gaps).

**Pre-bootloader firmware.** Boards running firmware older than the bootloader
work answer `0x00` with a normal protocol version but have no bootloader behind
them. The host distinguishes them with `REG_FW_VERSION` against
`FW_VERSION_BOOTLOADER_ENTRY`, the minimum version that honours
`REG_ENTER_BOOTLOADER`. Anything below that, including `FW_VERSION_NONE`, means
a one-time UPDI migration is required. This is a floor, not a guarantee: the
application cannot read the boot section, so a board whose bootloader was
somehow never installed would still report a bootloader-aware version. In
practice the two are installed together, and the host's marker probe catches the
mismatch before anything is erased.

## 9. Build and install

Three PlatformIO environments, all in the root `platformio.ini`:

- **`fb_bootloader_only`** — the bootloader alone. Bare-metal, no Arduino
  framework, linked into the boot section.
- **`fb_app_only`** — the application linked at `BOOTEND * 256`, with its vector
  table at the application start. This is the day-to-day development path: once
  the bootloader is installed it stays installed, so a developer re-flashes only
  the application over UPDI. `USING_OPTIBOOT` strips megaTinyCore's
  reset-flag and reset-loop `.init3` code, which the bootloader has already
  handled.
- **`fb_app_and_bootloader`** — the combined first flash. A post-build hook
  merges the two hex files, which never overlap, and a single
  `firmware/tools/flash_with_fuses.py` invocation writes the merged image **and**
  the `BOOTEND`/`APPEND` fuses over UPDI with `pymcuprog`.

A fourth environment, `fb_legacy_no_bootloader`, builds the application at
`0x0000` with no bootloader at all. It is only for boards that are not getting
the bootloader.

So bringing up a blank chip is one action: select `fb_app_and_bootloader` and
upload, using the same physical setup as
[ABOUT_UPDATING_FIRMWARE.md](ABOUT_UPDATING_FIRMWARE.md). That same combined
upload is the recovery path if a board is ever left in a state I2C cannot reach.

## 10. Host side

### The ESPHome component

`esphome/components/fader_buddy/` embeds a packaged application image at codegen
time and drives the update over I2C. Configuration and usage are documented in
[ABOUT_ESPHOME_INTEGRATION.md](ABOUT_ESPHOME_INTEGRATION.md); this section
covers how it works.

**What gets packaged.** Only the application. The image is the exact
page-aligned APPCODE bytes as a raw `.bin`, produced by
`firmware/tools/export_app_image.py`.

**Where the version comes from.** `FW_VERSION` is baked into the image at a
fixed address, the last two bytes of flash (`BL_APP_META_ADDR` in
`bootloader_protocol.h`, `FW_VERSION_FOOTER` in `firmware/src/main.cpp`).
Because the application section always runs to `FLASHEND`, that address never
moves as the application grows. The component reads the version straight from
the packaged `.bin`, so it cannot drift from what the flashed application will
report. The whole-image CRC16 is not baked in, because a CRC cannot cover
itself; it is computed at ESPHome build time from the same bytes.

**Embedding.** `to_code()` emits the image as a `static const uint8_t[] PROGMEM`
array. The component is `MULTI_CONF`, and many faders normally run the same
firmware, so the blob is emitted once per distinct image and shared across
instances rather than duplicating roughly 14 KB per fader.

**The sequence** is the same one the jig uses: probe register `0x00` → if not
already resident, `REG_ENTER_BOOTLOADER` and wait for the marker → `ERASE_APP` →
stream pages → whole-image `GET_VERSION_CRC16` → `RUN_APP` → re-read
`REG_FW_VERSION` to confirm.

**It runs a slice at a time from `loop()`.** `update_tick_()` walks an
`UpdateStage` enum, one stage per call; `update_firmware()` only arms the state
machine and returns. The transfer takes seconds, and blocking for that long
would starve the API and WiFi, and would make progress reporting impossible,
since queued entity states are only flushed from the loop. Three details make
the slicing work:

- **Page streaming is time-budgeted**, not one page per tick. `UPDATE_WRITE`
  keeps writing until `UPDATE_WRITE_BUDGET_MS` is spent, then yields. One page
  per tick would turn a 230-page image into about 4 seconds of pure latency.
- **The two long stalls are split into "ask" and "poll"** — erase and
  whole-image CRC. Both leave the target unable to answer for hundreds of
  milliseconds, and waiting for them inline would have been the one thing still
  blocking the loop.
- **Every polling stage carries a deadline**, compared wraparound-safe.

`update()` early-returns while an update is in flight, since a fader in its
bootloader has no `REG_STATE` to read.

**Guard rails:**

- **Only on a version mismatch.** A fader already running the packaged version
  is a no-op, reported as success.
- **No attempt cap, and no retry.** A failed update is reported and forgotten;
  nothing retries it and no counter persists. That only needs revisiting if
  updates ever become automatic — a loop that retries by itself needs a stop,
  but a human pressing a button already is one.
- **Never interrupt the user.** The run waits, bounded, for the fader to leave
  `MODE_INPUT_ACTIVE` before taking the bus, and reports failure if it is still
  in use.
- **One fader at a time.** A class-static flag refuses a second concurrent
  update across all instances. It is claimed before the first tick and held for
  the whole run, which matters because the sequence is interruptible: without
  it, a second fader could start in a gap between the first one's slices.
- **Manual only.** There is no autoupdate mode. An update runs only when a human
  presses the button or an automation calls the action.

### The production jig

`production_tools/programAndTest/` is the reference implementation and the
regression test. Every board that goes through the jig exercises the full update
path:

- `TEST_FW_BOOTSTRAP` UPDI-flashes the DUT with the **current bootloader, built
  from source on that run**, plus a fixed `FW_VERSION=0` application. That
  establishes "a board with a bootloader, running an old app".
- `TEST_FW_I2C_UPDATE` then drives `REG_ENTER_BOOTLOADER` from that running old
  application and updates it to the current application over I2C.

Building the bootloader fresh on every jig run is deliberate. A checked-in
bootloader image would silently ship a stale bootloader on every board flashed
after a bootloader change, and the bootloader is the one part that cannot be
fixed later over I2C. See
`production_tools/programAndTest/factory_test_images/README.md`.

## 11. Known gaps

Everything below is absent from the current implementation, not broken in it.

- **App validity is only a reset-vector check.** `app_is_valid()` checks that
  the reset vector is not blank. It does not catch a partially written image
  whose first page happened to land. Closing this means a linker-placed CRC
  footer (image length + CRC16 at the end of APPCODE) that the bootloader
  recomputes on boot, reusing the CRC16 already used for post-write verify.
  Streaming page 0 last would also help, since an interrupted update would then
  leave the reset vector blank. Until then, the TP5 strap is the recovery path,
  and it needs physical access.
- **No command timeout in the resident bootloader.** A host that abandons an
  update mid-stream leaves the bootloader resident forever. A watchdog or
  command timeout would let it recover on its own — jumping to the application
  if one is valid, otherwise resetting the TWI interface and continuing to
  serve. On a shared bus this matters more than it would on a point-to-point
  link.
- **No host-side bus recovery.** Neither the jig nor the ESPHome component
  recovers the master after a transaction timeout (`Wire.end()`/`begin()`, or
  clocking nine SCL pulses). This cannot rescue a *slave* holding SCL low, but
  it would protect against other stalls.
- **`ERASE_APP` does not blank pages beyond the new image.** It erases only the
  reset-vector page, and streaming rewrites only the pages the image covers. If
  a new image is smaller than the old one, stale bytes remain above it. This is
  harmless today, since the CRC verify covers exactly the streamed range, but it
  would matter for a CRC footer over the whole section.
- **Unvalidated on hardware:** the combined `fb_app_and_bootloader` upload onto
  a truly blank chip, and updating a multi-fader chain one fader at a time
  without disturbing the others. The individual pieces of both are validated;
  the combinations are not.
- **No CI coverage.** There is no hardware in CI, so every claim above was
  validated on the bench or by the jig.

## 12. Implementation notes

Details that are not obvious from the code, and that are likely to trip up the
next person working in this area.

**The address jumpers decode backwards from the port bits.** The board nets are
`PC0 = A2`, `PC1 = A1`, `PC2 = A0`, and a fitted jumper pulls its pin low, so a
fitted jumper *sets* its address bit. The bootloader and the application must
decode this identically — `twi_slave_init()` here and `setup_i2c()` in
`firmware/src/main.cpp` — because a mismatch does not fail loudly: the fader
simply answers on a different address once it enters the bootloader, and only
for some jumper settings. Reversing the three bits swaps offsets 1↔4 and 3↔6
and leaves 0, 2, 5 and 7 looking perfectly fine, so half a bench of boards works
and the rest vanish exactly when a host tries to update them.

**The bootloader must raise the main clock itself.** The reset default is
OSC20M divided by 6 — `CLKCTRL.MCLKCTRLB` comes up with `PDIV` = 6X and `PEN`
set — so CLK_PER is 3.33 MHz, not the 20 MHz the application runs at. That is
not just slow: the TWI slave is synchronous, and §26.3.2.1 requires
f_CLK_PER ≥ 10 × f_SCL, capping the bus at 333 kHz. A host on the common
400 kHz was out of spec for the whole time a fader sat in its bootloader, which
looks like intermittent NAKs and dropped frames during precisely the operation
that has to work. `run_at_full_speed()` clears the prescaler as the first thing
`main()` does, and `jump_to_app()` restores the reset value on the way out.
Note that the LED heartbeat is *not* affected either way — it runs off the RTC's
own 32.768 kHz oscillator rather than CLK_PER — but the two busy-wait loops
(pull-up settle, strap sampling) are, and were written against 20 MHz.

Bootloaders already on boards keep the old behaviour, since the boot section is
not field-updatable. If updates over I2C are flaky on such a board, drop the
host bus to 100 kHz or reflash the bootloader over UPDI.

**`PIEN` must be set on the TWI slave.** `TWI0.SCTRLA` needs
`TWI_PIEN_bm | TWI_ENABLE_bm`. Per datasheet §26.5.9, `PIEN` gates whether
`APIF` is raised on a Stop condition — the *flag*, not merely the interrupt.
The bootloader processes every master-write command at Stop, so without `PIEN`
commands like `SET_PAGE_ADDR` and `SEND_FRAME` are silently dropped while the
hardware still byte-ACKs them. Reads keep working, because they are processed at
the repeated-start address match, which raises `APIF` regardless. `DIEN` and
`APIEN` gate only interrupts and stay off, since there is no ISR.

**Every TWI event must end with one `SCMD` write.** `APIF` and `DIF` can only be
cleared by writing `SDATA` or `SCMD`; writing `SSTATUS` does not clear them. An
error path that clears flags and returns without issuing an `SCMD` leaves
`CLKHOLD` asserted, which holds SCL low and wedges the bus for everyone.
`COLL` co-occurs with `APIF`/`DIF` at the end of a slave transmit, so it must be
folded into the master-read completion check rather than handled as a separate
early return. `twi_service()` follows megaTinyCore's polled handler: compute one
action, always write `SCTRLB` at the end.

**Do not bulk-erase the application section.** Roughly 224 back-to-back
standalone `ER` commands leave the NVM controller silently unable to write:
subsequent `ERWP` commands no-op with no `WRERROR` set. A single erase is fine,
and many `ERWP` operations are fine. This is why `erase_app()` erases only the
reset-vector page. The exact silicon mechanism is unknown.

**The bootloader cannot trust an immediate read-back of what it just wrote.**
Reading mapped flash right after a write can return the page-buffer value rather
than what is actually in flash. Use a UPDI read as ground truth, or re-read
after other NVM activity.

**UPDI flash readback is the most useful debugging tool here**, because it is
independent of the I2C path. RAM readback is useful too but needs care: confirm
with a sentinel value that the read itself does not reset the part, since unlike
flash, RAM reflects boot state if the tool resets it.

**The entry token is at `0x3F00`, not the top of RAM.** An address near `RAMEND`
sits where the stack starts and would be clobbered by the bootloader's own
startup pushes before it could be read.

**Useful CRC16 signatures.** CRC16-CCITT over the whole application image, for
classifying a bad verify without reaching for UPDI: an all-`0xFF` section (the
write never landed) and an all-`0x00` section each have their own fixed value,
as do byte-swapped writes and even/odd-byte-only writes. Compute the expected
value for the current image size with the same `crc16_ccitt()` the packaging
tools use (`firmware/tools/fb_image/`).

**`i2c_data.h` and `bootloader_protocol.h` are hand-synced across copies** —
firmware, `esphome/components/fader_buddy/`, the jig, and the WebHID JS
constants. `ci/util/check_i2c_data_sync.py` enforces the C copies on every push;
the WebHID copy is still on you.

## Related documentation

- [ABOUT_UPDATING_FIRMWARE.md](ABOUT_UPDATING_FIRMWARE.md) — UPDI flashing, the
  bootstrap and recovery path.
- [ABOUT_ESPHOME_INTEGRATION.md](ABOUT_ESPHOME_INTEGRATION.md) — configuring and
  triggering updates from a host.
- [firmware/src/shared/bootloader_protocol.h](firmware/src/shared/bootloader_protocol.h)
  — the wire protocol and memory map.
- [firmware/src/shared/i2c_data.h](firmware/src/shared/i2c_data.h) — the
  application register map, including `REG_ENTER_BOOTLOADER` and
  `REG_FW_VERSION`.

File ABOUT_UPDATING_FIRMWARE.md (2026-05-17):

## Firmware Flashing

If you purchase a [FaderBuddy PCB assembly from Bezek Labs](bezeklabs.etsy.com/listing/4506790932), it will come with firmware already uploaded and tested, so you won't need to flash any firmware to get started. You can use these instructions if you'd like to update the firmware later.

If you [assemble your own](ABOUT_PCB_FABRICATION.md) FaderBuddy PCBs or purchase an assembled PCB from JLCPCB, you'll have a blank ATtiny1616 microcontroller, so you MUST flash the firmware yourself using a UPDI programmer before you can use it. This only needs to be done once per board (unless you want to update the firmware later).

The [Adafruit UPDI Friend](https://www.adafruit.com/product/5879) is a recommended UPDI programmer, but you can also build an UPDI programmer with a USB->Serial adapter and a few other components (see a comprehensive overview from SpenceKonde [here](https://github.com/SpenceKonde/AVR-Guidance/blob/master/UPDI/jtag2updi.md#a-note-on-breakout-boards)).

### Connecting the UPDI Friend

On the back of the FaderBuddy PCB, there are three through-hole test points labeled for UPDI programming, laid out at 0.1" spacing. You can solder on standard pin headers for repeated use, or simply hold jumper wires against the pads for a one-time flash.

Connect the Adafruit UPDI Friend to the test points as follows:

| UPDI Friend wire | FaderBuddy pad |
|---|---|
| Black (GND) | VIO **-** |
| Red (VCC) | VIO **+** |
| White (UPDI) | **U** |

FaderBuddy wiring(6)

### Flashing Steps

1. **Install PlatformIO:**

   If you don't already have PlatformIO installed, the easiest way is via VS Code: install the [PlatformIO IDE extension](https://platformio.org/install/ide?install=vscode).

2. **Connect the UPDI Friend** to the FaderBuddy board's UPDI and GND pads, and plug it into your computer via USB.

3. **Build and upload the firmware:**
   Use the "Upload" option in the PlatformIO extension. PlatformIO will automatically download the required toolchain, compile the firmware, and upload it to the ATtiny1616 via the UPDI Friend.

4. **Verify** the board is working by connecting it to an I2C bus -- it should appear at its configured address (default 0x20). You can verify with the ESPHome I2C scan (`scan: true`) or the WebHID debug tool if you have an MCP2221.

### Troubleshooting Firmware Upload

- **"No device found" or upload fails:** Check your UPDI and GND connections. UPDI requires only a single data line plus ground.
- **Wrong serial port:** PlatformIO should auto-detect, but you can set the upload port explicitly in `platformio.ini` or via command line: `pio run --target upload --upload-port /dev/ttyUSB0`
- **Permission denied (Linux):** You may need to add your user to the `dialout` group: `sudo usermod -a -G dialout $USER` (then log out and back in).

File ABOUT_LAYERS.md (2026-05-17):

# FaderBuddy Layers Architecture

## Overview

The FaderBuddy system implements **8 independent layers** per physical fader, allowing a single fader to represent multiple logical controls. Each layer maintains its own position and haptic configuration, enabling use cases like controlling multiple Home Assistant entities from one fader.

For example, consider a fader that can control both lamp brightness and fan speed. The host might apply this layer configuration:
- Layer 0 (lamp brightness)
  - Haptic mode: smooth
- Layer 1 (fan speed)
  - Haptic mode: 4 detents (off, low, medium, high)

When the active layer is 0 (lamp brightness), the user will feel smooth fader motion and the host will see updates in layer 0's position data. If the host tells FaderBuddy to switch to layer 1 the fader will move to the last-known layer 1 (fan speed) position. Now if the user interacts with the fader they will feel the haptic "snaps" between the 4 available positions, and the position will be reflected in layer 1 data.

The FaderBuddy internally handles layer-change mediation with user interactions, which means that a host controller command to switch layers while the user is touching/moving the fader will avoid fighting with the user and will prevent applying an incorrect position to the wrong layer.

In the example above, if the user is still moving the fader when the host requests a change from layer 0 to layer 1, the FaderBuddy will stay in layer 0 and the user will continue to feel smooth motion and the position will still be written to layer 0. Once the user finishes their interaction the FaderBuddy will automatically apply the pending layer change to layer 1, with the fader moving to the layer 1 fan speed position and the detents will be turned on.

The firmware also supports host-written position updates to the non-active layer. For example, if the fan speed is changed remotely from "off" to "high" while the fader is in lamp brightness mode, the FaderBuddy will remember this and move the fader to the "high" position the next time the fan speed layer is re-activated.

If you want to control more than 8 things with a single fader, you can have the host manage "virtual" layers with a ping-pong approach on 2 firmware layers instead of giving each thing its own dedicated firmware layer. In order to change virtual layers, the host would first write to the non-active firmware layer with the last-known position of the target virtual layer, write the virtual layer's desired haptic config, and then send the command to switch active layers. Each layer change would alternate which of the 2 firmware layers is active.

## Key Concepts

### What is a Layer?

A layer is an independent logical control context stored in the fader's volatile memory and fully managed within the fader firmware. Think of it as a separate "preset" that the fader can switch between:

- **8 layers per fader** (indexed 0-7)
- **Per-layer restore position**: Each layer remembers where its last-known "target" position is
- **Per-layer haptic config**: Each layer can have different haptic feedback (smooth, detents, magnetic endpoints)
- **Independent state**: Layers are isolated - changing one doesn't affect others

### Active Layer

Only one layer is **active** at any time. The active layer determines:
- What position the physical fader should be at
- What haptic feedback the user feels
- Which layer's state is reported in the STATE register

The firmware manages layer switching and ensures smooth transitions between layers.

## Architecture

### Firmware-Managed Layers

Layer state lives entirely in the **ATtiny1616 firmware**. The firmware maintains:

- Haptic configuration for each of the 8 layers
- Target/restore position for each of the 8 layers
- Currently active layer index (0-7)
- Pending layer change (for deferred switching)

**Firmware location**: `firmware/src/main.cpp`

### I2C Protocol

Layer operations use **layer-addressed registers**:

- **REG_ACTIVE_LAYER**: Read/write the active layer index (0-7)
- **REG_LAYER_TARGET**: Read/write target position for a specific layer
- **REG_LAYER_HAPTIC_CONFIG**: Read/write haptic config for a specific layer

See `firmware/src/shared/i2c_data.h` for complete protocol definitions including register addresses, STATE register bit fields, and haptic configuration format.

#### Layer-Addressed Register Protocol

Reading/writing specific layers uses a protocol where the layer index (0-7) is included in the transaction:

**Write to a layer's target position:**
```
I2C Write: [REG_LAYER_TARGET, layer_index, position_value]
```

**Read a layer's haptic config:**
```
I2C Write: [REG_LAYER_HAPTIC_CONFIG, layer_index]  // Set register and layer to query
I2C Read:  [config_bytes...]                       // Firmware returns config for specified layer
```

### STATE Register

The STATE register includes the active layer index (0-7) as one of its packed fields. All state reports indicate which layer is currently active, allowing the host to correlate position/touch/mode information with the correct layer context.

## Layer Switching Behavior

### Deferred Layer Changes

Layer changes are **deferred** during user input to prevent interrupting the user:

**MODE_INPUT_ACTIVE** (user is touching/moving fader):
- Layer change request is stored as pending
- Firmware continues operating on current layer
- When user releases fader and it transitions to INPUT_IDLE, the pending layer change applies

**MODE_INPUT_IDLE or MODE_REMOTE_MOVEMENT_IN_PROGRESS**:
- Layer change applies immediately
- Fader moves to the new layer's restore position
- Remote movements can be interrupted by layer changes

**MODE_SELF_CALIBRATION**:
- Layer change deferred until calibration completes
- Applies when calibration finishes

**MODE_ERROR**:
- Layer change requests are ignored (not deferred)
- Error must be cleared before layer switching is allowed

### Restore Position Updates

Each layer's restore position is updated automatically:

**During user input** (MODE_INPUT_ACTIVE):
- `restore_position[active_layer]` continuously tracks actual fader position
- Captures the user's intended position for this layer

**When starting remote movement**:
- `restore_position[active_layer]` set to the target position
- Not updated during the movement itself

**When writing to inactive layer**:
- `restore_position[layer]` updated without moving physical fader
- Position restored when switching to that layer

## ESPHome Component

The ESPHome component acts as a **thin protocol wrapper**, allowing static initial layer configurations to be defined in yaml, and forwarding layer operations to the firmware:

**Component location**: `esphome/components/fader_buddy/`

### Key Methods
These can be called from within lambdas.

```cpp
// Switch to a different layer (may be deferred by firmware)
void set_active_layer(uint8_t layer_index);

// Get currently active layer from firmware
uint8_t get_active_layer() const;

// Set target position for a specific layer
void remote_move_to(uint8_t position, uint8_t layer = 0);

// Get restore position for a specific layer
uint8_t get_position(uint8_t layer = 0) const;

// Set haptic configuration for a specific layer
void set_layer_haptic_config(uint8_t layer, uint8_t mode,
                              uint8_t detent_count, uint8_t detent_strength);
```

### Automation Triggers

All triggers include the active layer index:

```yaml
on_manual_move:
  - lambda: |-
      // x = position, layer = active layer index
      ESP_LOGD("fader", "Layer %d moved to %d", layer, x);

on_touch_change:
  - lambda: |-
      // x = touch state (bool), layer = active layer index

on_double_tap:
  - lambda: |-
      // layer = active layer index when double-tap occurred
```

### Example: Two-Light Controller

This example shows a single fader controlling two different lights based on the active layer:

```yaml
esphome:
  name: fader-controller

fader_buddy:
  - id: my_fader
    address: 0x20
    update_interval: 10ms

    # Configure different haptic feels per layer
    layer_haptics:
      - layer: 0
        mode: smooth
      - layer: 1
        mode: detents
        detent_count: 10
        detent_strength: 4

    # When user moves the fader, update the appropriate light
    on_manual_move:
      - lambda: |-
          float brightness = x / 2.55;  // Convert 0-255 to 0-100

          if (layer == 0) {
            auto call = id(living_room_light).turn_on();
            call.set_brightness(brightness / 100.0);
            call.perform();
          } else if (layer == 1) {
            auto call = id(bedroom_light).turn_on();
            call.set_brightness(brightness / 100.0);
            call.perform();
          }

light:
  - platform: homeassistant
    id: living_room_light
    entity_id: light.living_room

  - platform: homeassistant
    id: bedroom_light
    entity_id: light.bedroom

# Buttons to switch between layers
binary_sensor:
  - platform: gpio
    pin: GPIO4
    name: "Living Room Button"
    on_press:
      - fader_buddy.set_active_layer:
          id: my_fader
          layer: 0

  - platform: gpio
    pin: GPIO5
    name: "Bedroom Button"
    on_press:
      - fader_buddy.set_active_layer:
          id: my_fader
          layer: 1
```

When a layer switch occurs, the fader automatically moves to that layer's last position, so switching to "bedroom" will restore the bedroom light's previous brightness setting.

If you wanted the motor faders to respond to external changes in light brightness, you could add a homeassistant sensor that monitors the brightness and calls remote moves on the appropriate layer for each light.

## Haptic Configuration

Each of the 8 layers has its own haptic configuration containing:

- **Haptic mode**: smooth, smooth with magnetic endpoints, or detents
- **Detent count**: Number of detent positions (for detents mode)
- **Detent strength**: Force feedback strength

Haptic configs can be set statically in YAML or changed dynamically via actions.

## Example Use Cases

### Multi-Scene Control
- Layer 0: Living room lights
- Layer 1: Bedroom lights
- Layer 2: Kitchen lights
- Each layer remembers its last brightness setting

### Parameter Banks
- Layer 0-7: Different synthesizer parameters
- Switch layers to control different aspects of sound
- Each parameter can have different haptic feedback (smooth vs stepped)

### Mixing Scenes
- Store complete mixer states across layers
- Recall different mixes by switching all faders to the same layer
- Each scene preserves fader positions independently

## Implementation Details

### Firmware

**Layer management functions** (`firmware/src/main.cpp`):
- `request_layer_change()`: Handles layer change requests with deferral logic
- `apply_layer_change()`: Executes layer switch and initiates movement
- `write_layer_target()`: Handles target position writes for any layer
- `write_layer_haptic_config()`: Handles haptic config writes for any layer

**I2C handlers**: Implement layer-addressed register protocol using `queried_layer` state variable to track two-step read operations.

**Mode transitions**: Check for `pending_layer_change` when entering MODE_INPUT_IDLE and apply if present.

### ESPHome

**Configuration** (`esphome/components/fader_buddy/__init__.py`):
- Python schema for `layer_haptics` YAML configuration
- Code generation for actions and triggers with layer parameters

**Component** (`fader_buddy.cpp`):
- I2C wrapper methods that forward operations to firmware
- Trigger firing with active layer extracted from STATE register
- No layer state management - firmware is source of truth

## References

- **I2C Protocol and register definitions**: `firmware/src/shared/i2c_data.h`
- **Firmware implementation**: `firmware/src/main.cpp`
- **ESPHome component**: `esphome/components/fader_buddy/`
- **Complete example with display**: `esphome/examples/multi-fader-display.yaml`

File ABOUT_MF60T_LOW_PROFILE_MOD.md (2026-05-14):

# MF60T Low Profile Mod (Optional!)

The stock MF60T is unnecessarily deep/tall, but if desired, you can shave off a LOT of height when installing a FaderBuddy PCB with a little bit of work. This is only recommended for advanced users; most users should install the FaderBuddy PCB on an unmodified MF60T as intended.

Here's a side-by-side comparison:
IMG_0463 Large

## Step 1: Remove pin extensions/brackets
The MF60T comes with black plastic and metal pin extension brackets on both the 4 pins from the potentiometer, and on the 2 motor pins, designed to make PCBs (like the FaderBuddy) easy to attach - we'll be removing these to save space.
IMG_0443 Large

The 4-pin bracket can be pulled directly off the fader
IMG_0444 Large

And the motor pin extensions/bracket will need to be desoldered to be removed, leaving just the motor connections exposed (be careful not too apply too much heat to the motor coils during this step)
IMG_0446 Large

## Step 2: Prepare potentiometer pins 
You'll need to fold down this metal tab, which previously held the plastic bracket in place
IMG_0450 Large

Then, using sharp and sturdy cutters (the pins are steel, not soft copper!), shorten each of the 4 potentiometer pins with a diagonal cut. The diagonal cut is necessary because the metal pins are too wide to fit into the PCB through-holes once the narrow tips have been cut off.

Note: the pin lengths shown here are not the final length; I ended up shortening them further to get the very low profile seen in the final photos, but I forgot to take an updated photo.
IMG_0451 Large

The diagonally cut pins will fit into the PCB's through-holes - check the length and shorten further if needed (I shortened them more after taking this photo) before soldering in place.
IMG_0452 Large

## Step 3: Add motor wire extensions
Because the FaderBuddy PCB was designed to fit onto an **unmodified** MF60T, it will be too short and unable to directly solder to the motor pins on a modified MF60T.

I found that the easiest way to connect the motor is by adding a short wire extension to each, and specifically, it's easiest to assemble this by taking a wire, feeding it through the PCB and bending it appropriately to align with the motor pin, then soldering in place to the motor and PCB before finally cutting off the wire.
IMG_0457 Large

IMG_0461 Large

## Step 4: Admire your work
You now have a significantly lower-profile motorized fader! Good work!

IMG_0462 Large

IMG_0463 Large

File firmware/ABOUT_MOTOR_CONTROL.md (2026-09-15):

# About: motor control and closed-loop tuning

Notes for whoever next touches the movement code. Covers the plant model, why
the control law is shaped the way it is, what each constant does, and how to
re-measure everything on hardware.

Three files: `src/motor_control.h` holds the drive primitives and every `MOVE_*`
constant; `src/main.cpp` runs the control law and owns the mode state machine;
`src/motor_cal.cpp` measures the plant during self-calibration and re-derives
the gains from it.

## Units

Two different position scales appear in the code and in measurements:

- **ADC counts** (0-1023). What the firmware works in: `input_ewma`,
  `input_calib_min/max`, `target_adc`, all `MOVE_*` gains.
- **raw** (0-2046). What the `STATE` register reports, because ADC1 runs with
  2x accumulation. `raw = 2 * ADC`.

Full travel is about 1956 raw over 60 mm, so **1 mm is about 33 raw / 16 ADC counts**.

"Duty" always means the 0-254 value handed to `motor_set()`, matching the TCA0
split-mode period.

## The plant

Measured on a jig fader. Numbers vary between units; the shapes do not.

**It is a velocity source with a friction deadband, not a force source.**
Below a breakaway duty nothing moves at all. Above it, speed is roughly
proportional to duty. There is no useful "push gently" region: at breakaway the
speed jumps discontinuously to ~900 raw/s (Stribeck effect). This single fact
drives almost every design decision below.

**Breakaway duty depends strongly on PWM decay mode, not on frequency:**

| drive scheme | dir A (rising ADC) | dir B (falling) |
|---|---|---|
| fast decay @ 306 Hz | ~55 | ~75 |
| fast decay @ 19.6 kHz | ~190 | ~200 |
| slow decay @ 19.6 kHz | ~70 | ~90 |
| slow decay @ 39.2 kHz | ~68 | ~88 |

Direction asymmetry (~20 duty counts) is consistent and real; the two
directions get separate feedforward constants.

**Velocity above breakaway** rises ~58 raw/s per duty count going up, ~94 going
down. Full duty is ~16000 raw/s (~490 mm/s).

**Coast-down is first order with tau ~5 ms.** Stopping distance after drive is
cut is about `v * 6 ms`: 7 raw from 2300 raw/s, 80 raw from 12000 raw/s.
Braking (both low sides on) only shortens this by ~25% - the mechanism is
already heavily friction-damped, so **braking is not the anti-overshoot lever**.
Cutting drive early is.

## Why slow decay

The DRV8837 takes IN1/IN2 as 1/0 forward, 0/1 reverse, 0/0 coast, 1/1 brake.

- **Fast decay** (what the code used to do): PWM one pin, hold the other low, so
  each cycle alternates drive and coast. Winding current decays through the body
  diodes every cycle. At a high carrier the average current ends up far below
  what the duty implies, so low-duty torque collapses - hence the 190 breakaway
  in the table above.
- **Slow decay** (what `motor_set(..., slow_decay=true, ...)` does): hold the
  leading pin high from PORT, PWM the trailing pin between drive and brake, so
  its high fraction is the inverse duty. Current keeps circulating through the
  bridge, average current tracks duty, and low-duty torque survives.

This is why movement no longer drops the carrier to 306 Hz. That switch existed
purely to buy torque back, and it was the audible buzz. There is now one
permanently inaudible carrier (19.6 kHz) for everything.

**Haptics deliberately still use fast decay.** `HAPTIC_BASE_PWM` and
`get_strength_max_pwm()`'s 189 floor were tuned against the fast-decay force
curve. Switching haptics to slow decay would make them far stronger and change
the feel. If you ever do switch them, those constants must be retuned together.

## The control law

In `main.cpp`'s `motor_update()`, `MODE_REMOTE_MOVEMENT_IN_PROGRESS`:

```
error = target_adc - input_ewma
if |error| <= move_deadband:  brake, and start/continue the settle timer
else:
    v_ref = MOVE_VREF_SLOPE * error               # position loop
    |v_ref| clamped to the requested speed limit  # if one was requested
    |v_ref| floored at move_vel_min               # Stribeck floor
    u  = sign * (breakaway + |v_ref| / k)         # feedforward: plant inverted
    u += move_kv * (v_ref - velocity_ewma)        # velocity loop
    u += sign(error) * stiction_ramp              # stall escape
    drive_ceiling += MOVE_TAKEUP_RAMP_RATE * dt   # opens up from move start
    clamp |u| to (drive_ceiling + stiction_ramp), capped at MOVE_MAX_DUTY
```

**This is cascade control**: an outer position loop that asks for a velocity,
and an inner velocity loop that delivers it. Worth seeing in those terms,
because the previous flat form hid it - `u = KP*e - KD*v + FF` factors exactly
as `FF + KD*((KP/KD)*e - v)`, which is the same loop with `v_ref = (KP/KD)*e`
and gain `KD`. `MOVE_VREF_SLOPE` is that `KP/KD` ratio and keeps its old value
of 50/s; `MOVE_KV` is that `KD`.

Two things follow from writing it out, and both were real bugs in the flat form:

- **The inner loop's open-loop gain is `k * KV`**, not `KV`. `k` is the plant's
  ADC counts/sec per duty, so a higher-torque motor closes a proportionally
  hotter loop. Through the lag of the velocity estimate it goes underdamped and
  the fader oscillates *on velocity* - overshoot, brake, fall under,
  re-accelerate - which is not a position overshoot and does not look like one
  on the bench; it looks like the movement is chugging. `KV` is therefore
  scaled by `1/k` on a characterised unit, holding `k*KV` at the 1.16 the
  reference fader was tuned at.
- **The feedforward has to depend on the requested speed.** Inverting the plant
  gives `u_ff = breakaway + v_ref/k` exactly, so at steady state the feedback
  term is zero and the carriage simply travels at `v_ref`. A *fixed*
  feedforward instead commands whatever speed it commands - ~1100 ADC/s on the
  reference unit - and nothing slower is reachable without subtracting drive
  back off, which is what the old one-sided governor did. See "Optional speed
  limiting" below for why that misbehaved.

Five ideas, each solving a specific measured problem:

**Feedforward** is the plant model inverted: `breakaway + v_ref/k`. It supplies
both the breakaway duty and the duty that produces the wanted speed, so the
feedback term only has to correct the error in that model. Both halves are
measured per unit (see "Per-unit motor characterisation"); the compiled-in
defaults are the reference unit's values, so an uncharacterised fader behaves
as it always did.

**The velocity loop** is what prevents overshoot. Because `v_ref` is
`MOVE_VREF_SLOPE * error`, the controller is asking the carriage to be slower
the closer it gets, and drive falls away when it is travelling faster than
that. At 50/s against a coast limit of `1/tau ~ 200/s` it cuts about four
stopping distances short and coasts in. The old code had no such term and a
constant `+80` offset, so it drove at full authority right up to the deadband
and arrived at ~12000 raw/s - precisely the 58-80 raw overshoot it used to
show.

**Stiction ramp** fixes a genuine failure, not just feel. Because FF sits below
breakaway, small errors produce `FF + KP*error` below breakaway: the controller
commands motion it cannot produce, sits stuck outside the deadband, and after
8 s falls into `MODE_ERROR`. The ramp adds drive at `MOVE_RAMP_RATE` only while
commanded-but-stalled, capped at `MOVE_RAMP_MAX`. The cap also means a jammed
fader cannot wind up to full drive.

It is shed at `MOVE_RAMP_DECAY_RATE` once the carriage breaks free - fast
(~20 ms from full, far shorter than the coast time, so it still cannot
contribute to overshoot) but **not instantly**. Dropping up to 70 duty in one
tick is itself a relay, and sitting near `MOVE_STALL_VELOCITY` it chatters:
wind up, break free, dump the drive, stall again. With the feedforward now
derived to clear breakaway this should rarely engage at all during a normal
move; it covers measurement error, a cold or stiff unit, and the
uncharacterised case.

**Take-up ceiling** addresses belt backlash. A direction-reversed move otherwise
starts at full duty into slack: the rotor free-runs unloaded, then snaps taut
with an audible click and a jerk. The drive ceiling therefore starts at
`MOVE_TAKEUP_DUTY` and opens up to full over time at `MOVE_TAKEUP_RAMP_RATE`.

It is re-armed when a move is commanded in the opposite direction to the one in
progress, not on every write to `LAYER_TARGET`. Slack is only taken up on a
reversal, and a host that streams position updates - an LVGL slider being
dragged, say - retargets many times a second; re-arming on each of those would
hold the ceiling at the take-up duty for the whole gesture and cap the fader at
roughly half speed.

Three things about this are easy to get wrong, and all were bugs during
development:

- **It must be time-based, not gated on "are we moving yet".** While crossing
  the slack the rotor *is* moving, it just isn't loaded, so a velocity-gated
  ceiling lifts partway through the slack and full duty still lands on
  engagement. Time is the only available signal that doesn't depend on whether
  the belt has taken up.
- **The ceiling must stay above the feedforward.** It exists to stop drive
  stepping to full duty, not to suppress the feedforward. Set below it, it
  starves the term that gets the carriage moving: the fader stalls, waits for
  the stiction ramp, and breaks free abruptly - which hunts *and* makes the
  click worse. This regressed once already, when the feedforward was re-centred
  upward and the ceiling was left at its old value, which is why the derivation
  now computes the ceiling from the feedforward rather than storing it loose.

**Optional speed limit** (see below) is off by default and changes nothing when
unset.

## Fixed-rate loop and the velocity estimate

The control law runs on a `CONTROL_TICK_US` tick, not once per `loop()`.
Previously it ran every iteration, so gains and filter constants were per
*iteration* and drifted with however long touch processing took. `adc_drain()`
still runs every pass, folding every completed ADC conversion into `input_ewma`
on the `RESRDY` flag, so the position filter runs at the ADC's own constant rate
and never re-uses or tears a result.

Velocity is `d(input_ewma)/dt`, smoothed with a fixed time constant
`VELOCITY_TAU_S`. `input_ewma` is a float fed by a dithered ADC, so its
differences stay meaningful well below one ADC count - no need for a longer
baseline. **dt is measured from the previous execution, not the scheduled tick
time**; using the schedule silently skews the estimate whenever the loop cannot
keep up.

At 2 kHz the main loop still runs 6-8 kHz, leaving headroom for `ptc_process`.
At 250 us the loop saturates (loop rate == tick rate) with no margin; don't.

## Constants and how to change them

| constant | value | effect |
|---|---|---|
| `CONTROL_TICK_US` | 500 | 2 kHz. Higher rates gain little; the limit is friction, not sample rate. |
| `MOVE_VREF_SLOPE` | 50 | ADC/s of velocity reference per ADC count of error. The old `KP/KD`. Higher approaches faster and coasts in from further out. |
| `MOVE_KV` | 0.04 | Velocity loop gain. **Default only** - scaled by `1/k` on a characterised unit, because `k*KV` is what sets damping. |
| `MOVE_BD_RISING/FALLING` | 68 / 86 | Assumed per-direction breakaway duty. **Default only** - measured on a characterised unit. |
| `MOVE_K_DEFAULT` | 29 | Assumed ADC counts/sec per duty. **Default only** - measured. |
| `MOVE_VEL_MIN` | 560 | Floor on the velocity reference, and so on the feedforward's clearance above breakaway. |
| `MOVE_DEADBAND` | 8.0 | On-target window - the final error at which a move is declared arrived. Has a hard floor set by the plant - see below. Don't lower it. Derived per unit when characterised. |
| `MOVE_STALL_VELOCITY` | 60 | "Not moving" threshold, for the stiction ramp. |
| `MOVE_RAMP_RATE/MAX` | 250 / 70 | Stall escape strength. |
| `MOVE_RAMP_DECAY_RATE` | 3500 | How fast the stall escape sheds once moving. Finite, not instant - see below. |
| `MOVE_TAKEUP_DUTY` | 130 | Drive ceiling at move start. Must stay above FF, which is why it is derived from FF on a characterised unit. |
| `MOVE_TAKEUP_RAMP_RATE` | 1200 | Duty/sec the ceiling opens up. Lower = gentler start. |
| `MOVE_SPEED_SLOWEST_MS` | 700 | Full-travel time at host speed 0. The slow end of the validated window. |
| `MOVE_SPEED_FASTEST_MS` | 250 | Full-travel time at host speed 254. Faster than this the limiter stops biting. |
| `MOVE_TIMEOUT_TOLERANCE` | 20 | On timeout, error below this goes idle instead of `MODE_ERROR`. |

**The deadband has a floor set by the plant, not by taste.** Nothing moves
below breakaway, and at breakaway speed jumps straight to `v_jump`, so the
smallest correction the fader can make is that speed times the time it takes to
actually stop. A deadband below that floor cannot be satisfied: the controller
steps past the window in both directions forever, which looks like dithering at
the end of a move and eventually trips the movement timeout.

**That stopping time is not the coast time.** Coast-down is first order with
tau ~5 ms, so the carriage travels ~`v * 6 ms` after drive is cut - but the
controller does not cut drive the instant the carriage reaches the window. The
position filter and the control tick both have to notice first, and the
carriage keeps moving throughout. The reference unit's measured minimum
correction of 5-8 ADC counts at 450-560 ADC/s implies **9-18 ms end to end**,
two to three times the coast alone. `MOTORCAL_STOP_TIME_MS` is 15 ms for that
reason; sizing it at 6 produced a window a looser fader could not land in.

The error is worth making in the generous direction. Too small and the fader
dithers and times out; too large and the final position is slightly off, which
at these sizes is 2-5 LSB of the 8-bit position the host sees. The first is a
failure, the second is a rounding difference.

**`k*KV` is the speed/robustness tradeoff**, and it is the product that
matters, not `KV` alone. Lower is faster but rings sooner; higher is smoother
but slower to settle. Lowering it is mathematically equivalent to adding
carriage mass, since both make the carriage coast further, so a sweep of it
doubles as an inertia sweep. Measured on the jig at `k*KV` 1.16:

| effective inertia | 1.0x | 1.5x | 2.0x | 3.0x |
|---|---|---|---|---|
| reversals over the suite | 0 | 6 | 60 | 145 |

So the tuning tolerates roughly 1.5-2x the *total* moving inertia (carriage +
belt + reflected rotor inertia) before ringing returns. A plastic knob cap is a
few grams against that and is not a concern.

**This is why `k` has to be measured.** Leave `KV` at a fixed 0.04 and a fader
with `k` 60 instead of 29 runs `k*KV` of 2.4 - past the 2.0x column above, into
the regime where the loop rings. It shows up as velocity chugging during the
move rather than as position overshoot at the end, which is why it is easy to
misread as a speed-limiter problem.

## Tuning for hardware variance

This is an open source project and users run whatever fader they have - newer,
older, stiffer, looser. **The gains are therefore centred for the widest range
of hardware that still settles, not for best accuracy on one fader.** A slightly
missed target is barely noticeable. A fader that takes seconds to settle, or
times out into `MODE_ERROR`, is a dealbreaker. Optimise in that order.

The parameter that matters is how the feedforward compares to a given unit's
breakaway duty. Sweeping FF on the reference fader (breakaway 68 rising) shows
where moves stop settling:

| FF (rising) | 46 | 66 | 86 | 106 | 126 | 146 | 166 |
|---|---|---|---|---|---|---|---|
| moves that settled | 3/6 | 6/6 | 6/6 | 6/6 | 6/6 | 6/6 | 4/6 |

The window is roughly **66 to 146**, and it is very lopsided: only about 2 counts
of room below the reference breakaway, but ~78 above. So FF is set to 106, the
centre, rather than just under breakaway.

**Why too-low FF is the dangerous direction.** If FF lands below a unit's
breakaway, small errors cannot produce motion at all. The carriage stalls just
outside the deadband, the stiction ramp winds up, and when it finally crosses
breakaway the speed jumps discontinuously to ~900 raw/s - far too fast to stop
inside the window. It overshoots, the error flips sign, and the cycle repeats
until the movement timeout. That is what "motor active, oscillating, never
settles, then error" looks like in the field, and no deadband value fully
rescues it (tested up to 10 ADC counts).

**Why too-high FF is cheap.** `MOVE_TAKEUP_DUTY` caps drive while the carriage
is stalled, so an over-high feedforward is simply clamped instead of producing a
violent escape. Once moving, the D term absorbs the extra.

Measured tolerance at the shipping values, emulated by offsetting FF:

| unit breakaway vs reference | -40 | -30 | -20 | -10 | 0 | +10 | +20 | +30 | +40 |
|---|---|---|---|---|---|---|---|---|---|
| moves that settled | 7/7 | 7/7 | 7/7 | 7/7 | 7/7 | 7/7 | 7/7 | 7/7 | 6/7 |

So roughly **-40 to +30 duty counts** of breakaway spread is absorbed, with
worst-case steady-state error about 5.6 ADC counts (~0.35 mm, under 1.5 LSB of
the 8-bit position a host sees). The previous "just under breakaway" tuning
failed already at -10.

With FF centred, the design also stops being sensitive to the other constants:
every deadband from 3 to 9 and every take-up value from 70 to 150 settles 7/7.
That insensitivity is the point - if a change makes behaviour depend sharply on
one constant again, that is a regression even if the reference fader looks good.

### The other failure: a unit with LESS friction than the reference

Centring FF buys tolerance, but it does not make the design unit-independent,
and the failure at the low-friction end is the mirror image of the one above.
Near the target the slowest motion the controller can command is the
equilibrium of `u = KP*e + FF - KD*v` against the plant:

```
v_min = k * (KP*deadband + FF - breakaway) / (1 + k*KD)
```

and a move can only settle if `v_min * (stopping time)` fits inside the
deadband. On the reference unit (breakaway 68, k 29) that is
`29*(12 + 106 - 68)/2.16 = 670` ADC/s, about 4 counts of stopping distance
inside a 6 count window. On a unit whose breakaway is 40 and whose `k` is 40,
the same constants give `40*(12 + 106 - 40)/2.6 = 1200` ADC/s and 7.2 counts -
**larger than the deadband**. The fader cannot make a correction small enough
to land in the window, so it steps past, reverses, steps past again, and hunts
until the movement timeout.

That is what a brand-new, looser fader looks like on the bench: jerky, worst at
low commanded speeds, and never quite arriving. It is not fixable by raising the
deadband (the window would have to grow past what the host can see) and it is
not fixable by lowering FF globally, because that reintroduces the stall failure
on stiffer units. The gap between FF and breakaway has to be a *per-unit*
quantity.

## Per-unit motor characterisation

Self-calibration therefore measures the plant as well as the endpoints, and the
gains above become defaults that a characterised unit overwrites. Three numbers
per direction, in `MotorCalData`, persisted in the same EEPROM record as
`calib_min`/`calib_max` and reported at `REG_MOTOR_CAL` (0x12):

| measured | what it is |
|---|---|
| `bd` | breakaway duty - the duty at which the carriage first moves at all |
| `k` | ADC counts/sec of cruise gained per duty count above breakaway |
| `vjump` | the speed motion starts at once breakaway is crossed (Stribeck) |

**The measurement.** Each run parks at the end it will travel away from, brakes
for 200 ms (breakaway from a standstill is a different number from the duty
needed to *sustain* motion, so residual coast would corrupt it), then ramps duty
at ~80/sec until speed exceeds a motion threshold - that duty is `bd`. It holds
there for 40 ms taking the peak speed, which is `vjump`, then dwells at `bd+25`
and `bd+50` for 100 ms each, averaging the tail of each hold. The two dwell
speeds give a two-point fit for `k`. Runs alternate direction so each starts
where the last ended, two passes per direction, averaged. Anything implausible
(`bd` outside 10..180, `k` outside 8..90, a run reaching the calibrated ends)
discards the whole characterisation and keeps the compiled-in defaults - a
half-measured fader is worse than an un-measured one.

**What is derived** (`apply_motor_calibration`, in `motor_cal.cpp`):

```
breakaway, k  ->  straight into the feedforward, u_ff = bd + v_ref/k
KV            =  1.16 / k        (holds the inner loop's gain k*KV constant)
vel_min       =  clamp(1.25 * vjump, 200, 1500)
deadband      =  clamp(vel_min * 15 ms, 8, 20)
takeup        =  max(130, max_dir(bd + vel_min/k) + 20)
```

The compiled-in defaults are themselves a plant model - breakaway 68/86, `k`
29, `vjump` 448 - so there is one derivation rather than one per case, and an
uncharacterised fader provably runs the gains the constants were tuned to.

**On a unit that has never been characterised** - or whose measurement failed -
every derived value falls back to the constant in the table above, so the
behaviour is exactly the pre-1.2 firmware. `REG_MOTOR_CAL` byte 0 says which
case a fader is in.

## Flash budget

Worth knowing before adding anything here: **the ATtiny1616's 16 KB is the
binding constraint on this file**, and the I2C bootloader work reserves the top
2 KB, leaving **14336 bytes for the application**. The characterisation above
was written to fit that, which is why the measurement and the derivation are
integer throughout and the ramp is fixed point - the float versions of the same
logic cost roughly 1.3 KB more and did not fit.

Three unrelated savings were taken at the same time and are worth not undoing:

- `main.cpp` no longer includes `<megaTinyCore.h>`. Nothing used it, but its
  ADC-error helpers take `HardwareSerial&` default arguments, which under LTO
  pulls all of `UART0.cpp` - both USART ISRs and the `Print`/`HardwareSerial`
  machinery - into a build with `SERIAL_ENABLED` off. **800 bytes of flash and
  145 of RAM.**
- The heartbeat LED and `nSLEEP` go straight to `VPORTB` rather than through
  `digitalWrite()`, which is 160 bytes of pin lookup for two call sites.
- `onI2cRequest` builds multi-byte replies through `i2c_write_u16`/`u32` helpers
  instead of writing bytes out at each call site.

If a future change does not fit, measure before trimming: build, then
`avr-nm -S --size-sort -C .pio/build/fader_buddy/firmware.elf | tail -20`.

## Optional speed limiting

`LAYER_TARGET` (0x0E) takes an optional 4th byte capping the speed of the move.
Three-byte writes behave exactly as before, so this is backwards compatible and
does not change the protocol version.

A host that uses the byte should send it on every move, 255 included. The byte
sets the layer's *stored* speed, and a 3-byte write leaves that alone - so
falling back to 3 bytes for a full-speed move silently re-applies whatever limit
the layer last held. Send 3 bytes only to firmware predating the byte, which
ignores a 4-byte write entirely rather than moving.

The byte is a **unitless 0-255 speed**: 255 (the default) is unlimited, and 0 is
the slowest the mechanism moves smoothly. Values below 255 map linearly in
*velocity* across `MOVE_SPEED_SLOWEST_MS` .. `MOVE_SPEED_FASTEST_MS`, which are
stated as full-travel times because that is how the measurements below were
taken; the calibrated span turns each into a velocity.

The scale is deliberately unitless rather than a move time in ms. The usable
window is narrow and bounded at both ends by the plant - past the fast end the
limiter stops having any effect, past the slow end the mechanism stick-slips -
so a physical-units parameter mostly offers values that do nothing or cannot be
honoured. Mapping the whole byte onto the validated window means every value a
host can send does something, and the endpoints can be re-measured and moved
without changing the host-facing meaning of the byte. The cost is that "how
long will this move take" is no longer readable off the parameter, which is
honest: it was never accurate to better than ~15% anyway.

**It is realised by clamping the velocity reference**, and nothing else - one
line in the control law. Because the feedforward is `breakaway + v_ref/k`, a
lower reference directly means less drive, so the requested speed is produced
rather than fought for.

That is worth stating against what it replaced, because the earlier design is
an instructive failure. With a *fixed* feedforward the drive alone commanded
~1100 ADC/s regardless of the request, so clamping the error could never slow
the fader below that floor. Two extra parts were bolted on to work around it:
an error clamp to stop the P term saturating, and a **one-sided governor** that
subtracted drive once measured velocity exceeded the limit.

A one-sided correction puts the operating point exactly on its own
discontinuity: below the limit it contributes nothing at all, above it a lagged
correction. That is a limit-cycle generator, and it behaved like one - overshoot
the limit, brake hard, fall under, accelerate again, most visible at low
requested speeds where the cycle is a large fraction of the commanded velocity.
Both parts are gone; the plant-inverting feedforward removed the floor that
made them necessary.

Measured on the reference fader, requesting a full-scale time and timing a move
of 67% of full scale:

| requested full-scale | 250 ms | 400 ms | 600 ms | 800 ms | 1200 ms | 2000 ms |
|---|---|---|---|---|---|---|
| measured | 193 ms | 261 ms | 356 ms | 444 ms | 584 ms | 759 ms |
| vs expected | +16% | -2% | -11% | -17% | -27% | -43% |

**Usable range is roughly 250 ms to 700 ms of full-scale time**, hence those two
endpoints for the speed scale. Those figures were measured against the old
governor, whose tracking error ran to -43% at the slow end; the reference-clamp
form should track considerably better, since the feedforward now produces the
requested speed directly instead of being pulled back down to it. **Re-measure
that table** - it is the clearest single check that this change did what it was
meant to.

Beyond the slow end it saturates: there is a hard floor below which the motor
cannot sustain continuous rotation and creeps in stick-slip steps rather than
moving smoothly. Slower smooth motion is not reachable by tuning - it would need
a different drive scheme.

`move_vel_min` (1.25x the measured Stribeck jump, 560 ADC counts/sec by default)
is the clamp for that floor. It is applied to the velocity reference in the
control law, every tick, and nowhere else - not where the speed byte is decoded,
which would freeze it against a `move_vel_min` that calibration can change
afterwards. It is also the floor the reference is held at right next to the
target, which is what keeps the feedforward clear of breakaway for small errors.

Direction asymmetry is within about 7%.

Treat this as a *limit*, not a precise speed control - it is realised through
the friction-dependent plant, so exact velocity varies with the fader.

The lab jig's `sstep <from> <to> <speed> <log_ms>` command takes the same
unitless byte, so re-measuring the table above means picking speeds rather than
times.

## Reproducing the measurements

Two extra build environments exist for this; neither ships.

```bash
source ~/.platformio/penv/bin/activate

# ATtiny with REG_DEBUG_DRIVE / STATUS / GAINS (repo root)
pio run -e fader_buddy_lab -t upload

# ESP32 jig as a serial-driven measurement harness, replacing the
# production test state machine
cd production_tools/programAndTest && pio run -e lab -t upload
```

`env:lab` (`src/lab_main.cpp`) gives a line-oriented serial interface at
921600 baud: `step <from> <to> <ms>` captures a step response at ~3.2 kHz,
`openloop` and `stopdist` drive the bridge directly for system ID, `dbg` reads
control-loop internals, and `gain <index> <value>` overrides any tuning constant
at runtime so a gain sweep does not need a reflash per trial. Gain indices are
in `i2c_data.h` (`DEBUG_GAIN_*`); the reference slope, KV and deadband are
scaled by 1000.

Restore production firmware with `pio run -e fader_buddy -t upload` and
`pio run -e lilygo-t-display -t upload`.

The debug registers (0xF0-0xF2) are additive and compiled out unless
`DEBUG_DRIVE` is defined, so the protocol version is unchanged.

`REG_MOTOR_CAL` (0x12) is *not* debug-only and is present in production builds,
so a unit's measured breakaway, slope and jump speed can be read on a bench with
nothing but an I2C host attached - no jig, no lab firmware, no programmer. The
ESPHome component logs all of it at startup.

## Measurement gotchas

- **Derive the target from `calib_min`/`calib_max`, not from where the fader
  settles.** Read them via `REG_DEBUG_STATUS`. Inferring the mapping from
  settled endpoints bakes in the controller's own error - this produced a
  phantom 22 raw bias early in tuning.
- **The `STATE` raw ADC field is noisy while the motor drives.** Excursions of
  40+ raw appear there that the filtered `pos` field does not show; they are ADC
  noise, not motion. Median-filter before computing overshoot, and cross-check
  against `pos`.
- **Clear `MODE_ERROR` between automated trials.** One latched error otherwise
  makes every later trial report a frozen fader.
- Reported `err` from `REG_DEBUG_STATUS` is the same float the controller uses
  and is the ground truth for steady-state accuracy.

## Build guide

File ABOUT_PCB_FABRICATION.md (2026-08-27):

## PCB Fabrication
If you're in the US, the easiest way to get started is to purchase the FaderBuddy PCBA [pre-assembled and pre-flashed from the Bezek Labs store](bezeklabs.etsy.com/listing/4506790932), which also helps support development of this and other open-source projects. FaderBuddy boards from Bezek Labs have firmware installed and tested, and include the through-hold right-angle pin headers for chaining, so they're ready to go out of the box!

If you'd like to build your own, the FaderBuddy PCB is designed for easy JLCPCB SMT assembly. Note that an order from JLCPCB will NOT include firmware and will [require firmware flashing](ABOUT_UPDATING_FIRMWARE.md) before it can be used! All surface-mount components are placed by the factory, but the through-hole daisy-chain pin headers are omitted by default. You'll need to **order** and solder the pin headers separately (or add them to your JLCPCB assembly order):

| Item | Qty | Notes |
|---|-----|---|
| 5 pin right-angle male pin headers 0.1" spacing | 1 each | Included with Bezek Labs FaderBuddy boards, can be purchased separately from electronics suppliers like [LCSC - 40-pin break-apart headers](https://www.lcsc.com/product-detail/C429956.html)|
| 5 pin right-angle female pin headers 0.1" spacing | 1 each | Included with Bezek Labs FaderBuddy boards, can be purchased separately from electronics suppliers like [LCSC](https://www.lcsc.com/product-detail/C2935995.html) |

Use the files from the [latest release](https://github.com/scottbez1/FaderBuddy/releases) when ordering!

> [!CAUTION]
> The files below are auto-generated from the current (untested) design files, and are provided for design reference ONLY. They are NOT considered stable for manufacturing. Use the latest stable release linked above! 

Latest auto-generated (untested and likely broken!) artifacts⚠️:
- Review
  - [Schematic](https://motorfader-artifacts.s3.amazonaws.com/master/electronics/fader_buddy_main-schematic.pdf)
  - [Interactive BOM](https://motorfader-artifacts.s3.amazonaws.com/master/electronics/fader_buddy_main-ibom.html)
  - [PCB Packet](https://motorfader-artifacts.s3.amazonaws.com/master/electronics/fader_buddy_main-pcb-packet.pdf)
- Ordering (Configured for JLCPCB)
  - 1.6mm, any color, HASL lead-free
  - [Untested gerbers](https://motorfader-artifacts.s3.amazonaws.com/master/electronics/fader_buddy_main-jlc/gerbers.zip)
  - [Untested BOM csv](https://motorfader-artifacts.s3.amazonaws.com/master/electronics/fader_buddy_main-jlc/bom.csv)
  - [Untested CPL (POS) csv](https://motorfader-artifacts.s3.amazonaws.com/master/electronics/fader_buddy_main-jlc/pos.csv)

<details>
<summary><b>Advanced: panelized ordering (10 boards per panel)</b></summary>

Only relevant if you're ordering FaderBuddy PCBs in bulk - for a handful of boards, use the single-board files above.

For larger quantities there's also a panelized version of the board: a 2x5 grid of FaderBuddy PCBs (10 per panel) joined by mousebite tabs, surrounded by breakaway rails for the assembly machine. This is usually cheaper per-board than ordering the single board, since JLCPCB charges per panel, and it means less setup fee overhead for assembly.

The panel is generated automatically by CI using [KiKit](https://github.com/yaqwsx/KiKit); see `electronics/fader_buddy_main-kikit_panelize.json` for the panelization settings (grid size, tab/mousebite parameters, rail width).

- Ordering (Configured for JLCPCB) - when ordering, indicate the boards are panelized by the customer, 10 boards per panel
  - [Untested panelized gerbers](https://motorfader-artifacts.s3.amazonaws.com/master/electronics/fader_buddy_main-panelized-jlc/gerbers.zip)
  - [Untested panelized BOM csv](https://motorfader-artifacts.s3.amazonaws.com/master/electronics/fader_buddy_main-panelized-jlc/bom.csv)
  - [Untested panelized CPL (POS) csv](https://motorfader-artifacts.s3.amazonaws.com/master/electronics/fader_buddy_main-panelized-jlc/pos.csv)

<a href="https://motorfader-artifacts.s3.amazonaws.com/master/electronics/fader_buddy_main-panelized-3D_top.png">
    
</a>
<a href="https://motorfader-artifacts.s3.amazonaws.com/master/electronics/fader_buddy_main-panelized-3D_bottom.png">
    
</a>

To depanelize: snap off the top and bottom rails first, then the left and right rails, and finally separate the individual boards at the remaining mousebite tabs. Each board is held by one tab on each short edge plus two tabs along each long edge, all placed to keep the mousebite drills clear of the LEDs, test pads, tooling holes and nearby vias. Sand or file the leftover mousebite nubs flush if they interfere with mounting.

</details>

### Assembly

The PCB comes fully assembled from Bezek Labs LLC and JLCPCB. The only soldering required is attaching the PCB to the fader itself and the optional daisy-chaining headers, which are all through-hole connections:

- **2 connections** for the motor
- **4 connections** for the fader potentiometer
- 2 optional mechanical-only connections (I recommend skipping these)
- **5 connections** for the female daisy-chaining pin headers
- **5 connections** for the male daisy-chaining pin headers

No fine-pitch or SMD soldering is required.

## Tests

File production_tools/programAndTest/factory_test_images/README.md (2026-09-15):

# `old_app_fw0.hex`

A **fixed, checked-in** snapshot of the FaderBuddy application, built with
`FW_VERSION` forced to `0` and linked at the boot offset (`BL_APP_START`). It
stands in for "an old application already in the field." It is also built with
its heartbeat LED blink period doubled (half the normal blink rate), so a board
still running this old image is obvious at a glance.

This file holds the application **only**. The bootloader is not part of it.

## How the jig uses it

`TEST_FW_BOOTSTRAP` UPDI-flashes the DUT with two images in one go (see
`upload_firmware()` in `../test_host.py`):

1. the **current** bootloader, built from source on every run
   (`env:fb_bootloader_only`), and
2. this fixed old application.

`TEST_FW_I2C_UPDATE` then drives `REG_ENTER_BOOTLOADER` from that running old
app and updates it to the current application over I2C, exactly the way a real
in-field update works.

Building the bootloader fresh on every run is deliberate: a checked-in image of
the bootloader would silently ship a **stale bootloader** on every production
board flashed after a bootloader change. Only the application half is frozen,
because the test needs an old application to update away from.

## When to regenerate

Ordinary application changes must **not** touch this file -- the point is that
it stays fixed, so the test keeps exercising a real old-to-new transition.

Regenerate it only when the old starting state itself must change. The one case
that forces it is a **`BL_BOOTEND` change**: this image is linked at
`BL_APP_START`, so a different boot/app split leaves it at an address the new
bootloader will not jump to. Last regenerated for `BOOTEND = 0x06`.

## How it was generated

```bash
source ~/.platformio/penv/bin/activate
cd <repo root>   # where the root platformio.ini lives

# DEBUG_LED_BLINK_PERIOD_MS is doubled so the heartbeat LED blinks at half the
# normal rate -- a visual cue that a board is running this old image.
PLATFORMIO_BUILD_FLAGS="-DFW_VERSION=0 -DDEBUG_LED_BLINK_PERIOD_MS=1024" \
  pio run -e fb_app_only

cp .pio/build/fb_app_only/firmware.hex \
  production_tools/programAndTest/factory_test_images/old_app_fw0.hex
```

`FW_VERSION=0` is baked in via the `#ifndef FW_VERSION` guard in
`firmware/src/shared/i2c_data.h`, which otherwise defaults to the real current
version. The jig firmware's `OLD_FW_VERSION_FOR_TEST` constant
(`../src/main.cpp`) must match whatever value is used here.

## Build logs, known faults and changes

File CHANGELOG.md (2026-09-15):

# Changelog

FaderBuddy has three pieces that version independently: the **hardware**, the
**fader firmware** (ATtiny1616), and the **ESPHome component** that drives it
from a host. They are deliberately decoupled - a fader in the field can be
running older firmware than the host talking to it - so this file records what
each release changed and which combinations work together.

Separately, the **I2C protocol version** (reported at `REG_VERSION`) describes
the wire format of the register map. It is bumped only when the layout of an
existing register changes, never for additive features that an older host can
simply not use. Hosts should feature-detect on the firmware version rather than
the protocol version; see `firmware/src/shared/i2c_data.h`.

## Compatibility

Any firmware works with any component 0.2.0 or later - a component newer than
the firmware just logs a warning and skips features the firmware can't do
(e.g. move speed, motor characterisation). Component 0.1.0 needs the fader's
protocol version to match exactly, so it won't start against a future
firmware that bumps the protocol.

Firmware 1.0 predates `REG_FW_VERSION` and reports no version at all; hosts
that check it will read `0xFFFF` and should treat that as firmware 1.0.

---

## Hardware

### v1

All boards built to date - all are essentially identical, with minor changes
for production purposes.

- **v1.3.1** (pre-release) - adds a panelized gerber/BOM/CPL export for
  ordering 10 boards per panel. Only board change is two vias moved 0.75mm
  for mousebite clearance.
- **v1.3** - design files migrated to KiCad 10 (from 8); back silkscreen
  updated to say "FaderBuddy" instead of "motor fader".
- **v1.2** - fixed the JLCPCB BOM part number for the microcontroller, which
  had pointed at the ATtiny816 (1 ADC) instead of the ATtiny1616 (2 ADCs) this
  design needs.
- **v1.1 and earlier** (v0.1-v1.0) - initial bring-up; error in JLC part numbers.

---

## Firmware (ATtiny1616)

### 1.4 - unreleased

- Version bump only, for testing a firmware update.

### 1.3 - unreleased

- Firmware can be updated over I2C. A bootloader in the ATtiny1616's boot
  section receives the new application image, and `REG_ENTER_BOOTLOADER` (0x10)
  asks a running application to reboot into it. Installing the bootloader is a
  one-time UPDI flash, so boards already in the field need one more visit with a
  programmer before they can be updated in-band. See ABOUT_I2C_BOOTLOADER.md.
- Grounding test point TP5 across a reset holds the board in its bootloader,
  recovering a board whose application does not run or does not answer the bus.
- Fixed the bootloader decoding the three I2C address jumpers in the reverse
  order from the application. The board nets are `PC0 = A2`, `PC1 = A1`,
  `PC2 = A0`, so reversing them swaps address offsets 1<->4 and 3<->6 while
  leaving 0, 2, 5 and 7 correct. A board on one of the affected settings
  answered on a different address the moment it dropped into its bootloader,
  so a host would find nothing at the configured address and could not update
  it. Bootloaders already flashed keep the old decode - see below.
- The bootloader runs the main clock at its full 20 MHz. It had been leaving
  the reset default in place - OSC20M divided by 6, so 3.33 MHz - which put the
  TWI slave's 10x f_CLK_PER/f_SCL requirement at a 333 kHz ceiling. A host on a
  400 kHz bus was therefore out of spec whenever a fader was in its bootloader,
  showing up as intermittent NAKs and dropped frames during exactly the
  operation that needed to work. Since the bootloader is not field-updatable,
  boards already carrying one keep the old behaviour; run them at 100 kHz (or
  reflash the bootloader over UPDI) if updates over I2C prove flaky.

### 1.2 - unreleased

- Remote movement now uses cascade control (position loop sets a velocity
  reference, an inner loop realises it) with a friction feedforward derived
  from the plant model rather than a fixed duty. See
  `firmware/ABOUT_MOTOR_CONTROL.md` for why.
- Self-calibration now also characterises the motor (per-direction breakaway
  duty, speed/duty slope) and derives the feedforward, take-up ceiling, and
  on-target deadband from it, so tuning holds across faders with different
  friction or torque.
- New `REG_MOTOR_CAL` (0x12), reporting those measurements. Read-only and
  diagnostic.
- Calibration EEPROM format changed - the first boot after updating falls
  back to default endpoints until self-calibration is re-run.
- Self-calibration now returns the fader to the active layer's position using
  the newly measured endpoints. It previously re-used a target derived from the
  bounds it had just replaced, so the fader settled slightly off.
- The position nonce in `STATE` is now actually incremented on local input. It
  had no producer, so a user move that ended on the same 8-bit position as it
  started was invisible to the host.
- The backlash take-up ceiling is re-armed on a direction reversal rather than
  on every `LAYER_TARGET` write. A host streaming position updates previously
  held the fader at the take-up duty - roughly half speed - for the whole
  gesture.
- Detent haptics no longer pull toward the top of travel when the fader is
  below the calibrated minimum (reachable with a stale calibration).
- Fixed the hysteresis window being half-width when a move ended at the very top
  of travel, which made a fader parked there twice as likely to report spurious
  user input.

### 1.1 - unreleased

- Rewritten remote-movement control: PD on position with a per-direction
  friction feedforward, a stiction ramp, and a backlash take-up ramp. Moves are
  quieter and no longer overshoot. See `firmware/ABOUT_MOTOR_CONTROL.md`.
- `LAYER_TARGET` (0x0E) accepts an optional 4th byte setting move speed
  (0-255, 255 = full speed). Three-byte writes are unchanged, so this is
  backwards compatible.
- New `REG_FW_VERSION` (0x11), reporting a packed `(major << 8) | minor`.
  This is the first firmware that reports a version.
- Debug-only registers moved from 0x10-0x12 to 0xF0-0xF2, so production
  registers can keep growing from 0x10.
- On a movement timeout, a fader that is essentially in position now goes idle
  quietly instead of latching `MODE_ERROR`.

### 1.0

The last unversioned firmware - everything released before `REG_FW_VERSION`
existed. Protocol v5: firmware-managed layers, 16-bit haptic config, and the
layer-addressed registers.

---

## ESPHome component

### 0.3.0 - unreleased

- The hub now creates its own diagnostic text sensors - serial number and
  firmware version - so a bare `fader_buddy:` block reports what it is with no
  entity yaml at all. Names default to `<hub id> Serial Number` / `<hub id>
  Firmware Version`; override `name:`, or set `internal: true` /
  `disabled_by_default: true`, on the hub's `serial_number:` /
  `firmware_version:` key. Firmware version had no sensor before, only a log
  line.
- The hub also creates a **Self Calibration** button, so a fader can be
  recalibrated from Home Assistant without writing an automation around the
  `fader_buddy.run_self_calibration` action. `entity_category: config`, since
  pressing it drives the carriage to both ends for several seconds - HA files
  it with the device's settings rather than its controls. Rename it with
  `self_calibration: {name: ...}`, or hide it with `internal: true`.
- Faders can be updated over I2C, with no UPDI programmer. Point a fader at a
  released image with `firmware: "1.3"` (fetched from its GitHub release and
  pinned by sha256) or at a local build with `firmware_image:`, then install it
  with the `fader_buddy.update_firmware` action or the auto-created **Firmware
  Update** button. Updates are never automatic, and the button is only created
  when an image is configured. The outcome arrives on
  `on_firmware_update_result`. See ABOUT_ESPHOME_INTEGRATION.md.
- The firmware version text sensor reports update progress while one runs, and
  is re-read afterwards along with the serial number.
- **Deprecated:** `text_sensor: platform: fader_buddy`, to be removed in 0.5.0.
  It still works and still wins over the hub's own serial number sensor, so
  there are never two, but it now logs a deprecation warning. To migrate,
  delete the `text_sensor:` block and move any `name:`/`icon:` onto the hub's
  `serial_number:` key.
- Fixed `remote_move_to` at speed 255 re-using the previous speed limit. Full
  speed was sent as a 3-byte write, which leaves the layer's stored speed
  alone, so a move after any slower one silently kept the old limit. The speed
  byte is now sent on every move when the firmware supports it.
- Reads `REG_MOTOR_CAL` at startup and logs what the fader measured about its
  motor, or a note that it hasn't been characterised yet. Diagnostic only.
- Reports the fader's mode changes, which previously went unlogged entirely:
  self-calibration starting and finishing (re-reading `REG_MOTOR_CAL` on
  completion, so the run's own measurements are logged rather than the ones
  read at startup), and a warning whenever the fader latches `MODE_ERROR` -
  including a failed endpoint sweep, which was silent.
- The startup version probe is retried before giving up, and a fader with a
  configured firmware image that still doesn't answer no longer fails the
  component. Previously one NAK at boot - a fader still coming out of reset, a
  bus still settling behind a chain of them - marked the hub failed for the
  whole boot: both text sensors stayed Unknown and, because ESPHome runs
  neither `loop()` nor `update()` on a failed component, the firmware update
  that could have recovered it was refused and could not have run anyway. Such
  a fader is now re-probed on a doubling backoff - about 1, 3, 7, 15 and 31
  seconds after boot - and initializes itself whenever it turns up, and the
  **Firmware Update** button stays available for one that is wedged rather than
  absent. The backoff is bounded deliberately: a fader still silent after half
  a minute is absent rather than slow, and probing it once per poll forever
  would take the bus away from the faders that are working. A fader reporting a protocol older
  than v5 still fails the component: that firmware predates I2C bootloader
  entry (firmware 1.3), so UPDI really is the only way back, and the log now
  says so.
- Dropped the persistent failed-update attempt counter and its
  `max_update_attempts:` option. It existed to stop an automatic updater
  looping on a fader that never takes the image, and updates are manual only -
  a human pressing a button is already the stop. A failed update is reported
  and forgotten; press the button again to retry.

### 0.2.0 - unreleased

- `fader_buddy.remote_move_to` takes `speed:` (0-255), and `layer_haptics`
  takes `default_speed:` for moves that don't name one.
- Reads and logs the fader's firmware version at startup, and warns instead
  of silently doing nothing when a config asks for a move speed the fader's
  firmware can't honour (the move runs at full speed instead).
- Accepts a fader reporting a newer protocol version, warning instead of
  failing to start. Only an older protocol is still treated as incompatible.

### 0.1.0

The last unversioned component - everything before this file existed. Layer
management, haptic config, rate-limited triggers, the serial number text
sensor, and position/touch/double-tap handling.

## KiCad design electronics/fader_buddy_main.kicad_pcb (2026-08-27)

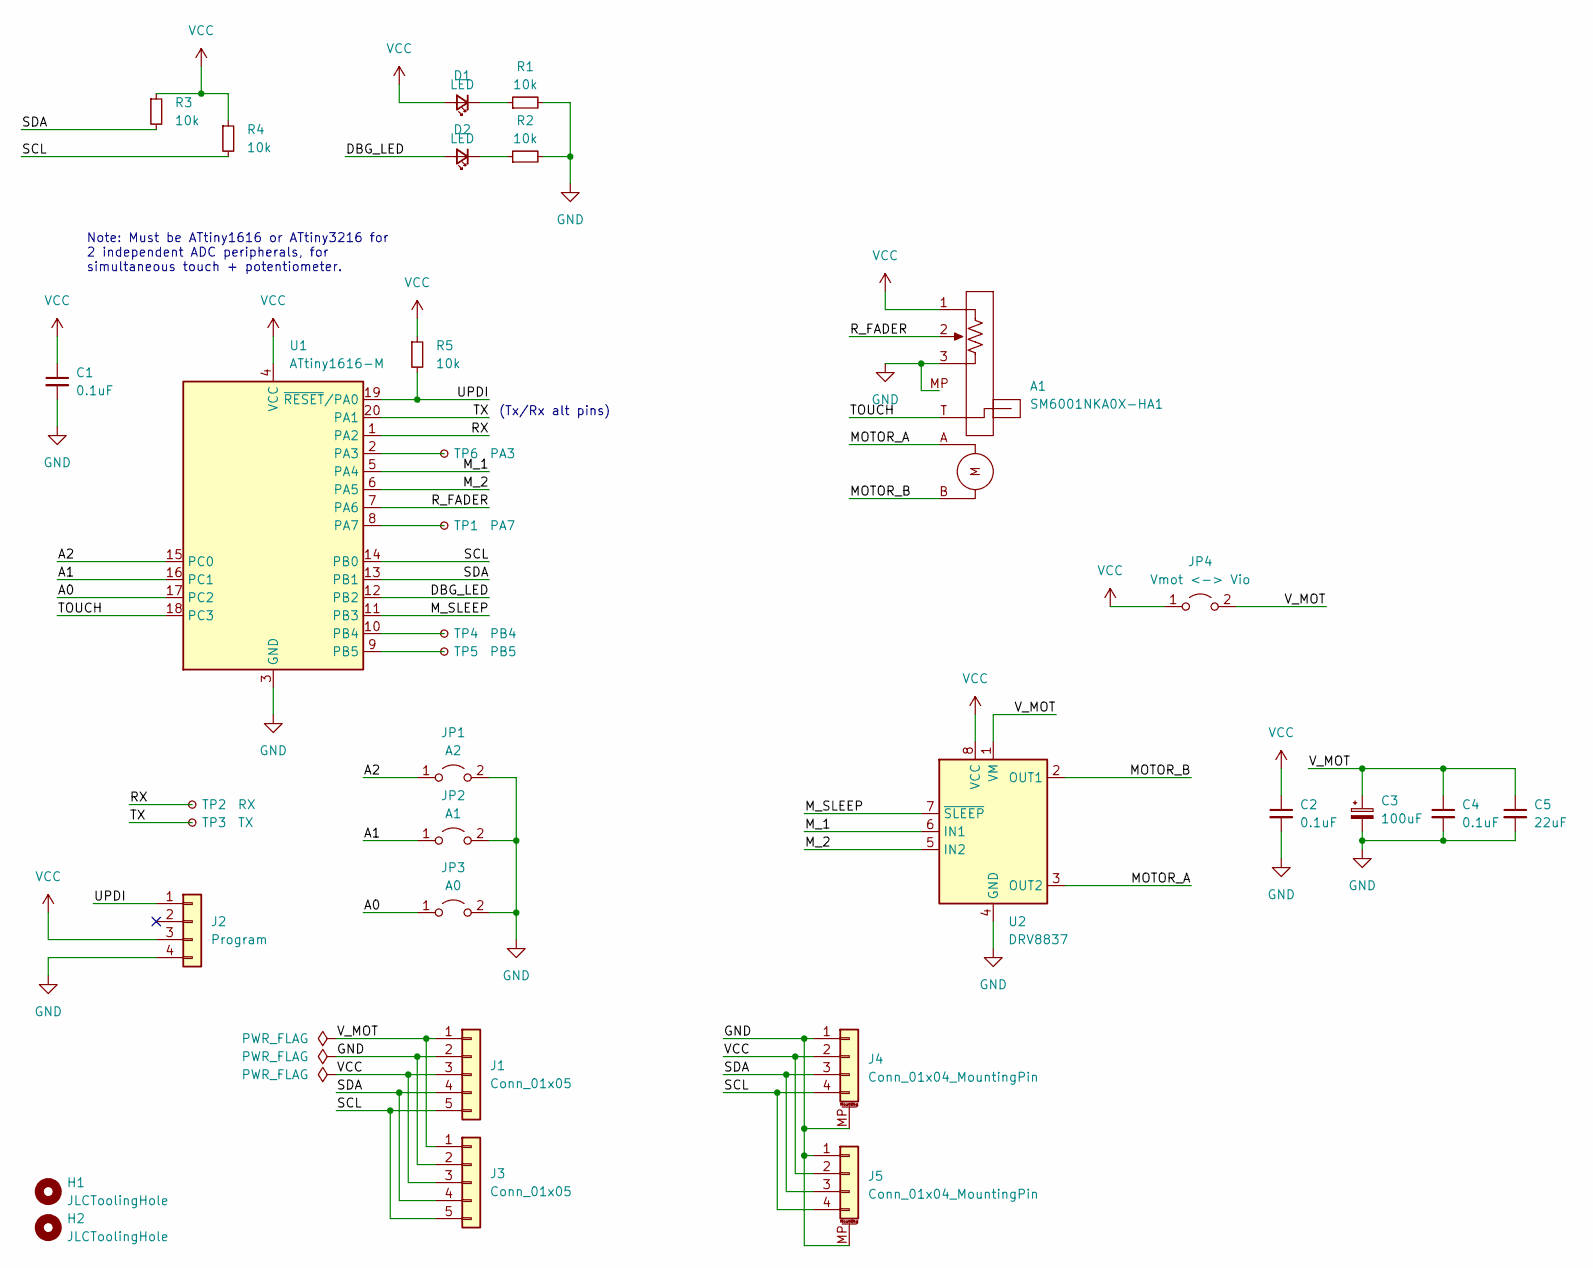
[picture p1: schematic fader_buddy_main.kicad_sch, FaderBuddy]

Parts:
A1: SM6001NKA0X-HA1
C1, C2, C4: 0.1uF; C_0603_1608Metric; LCSC C14663
C3: 100uF; CP_Elec_6.3x5.4_Nichicon; LCSC C340722
C5: 22uF; C_0805_2012Metric; LCSC C602037
D1, D2: LED; LED_0603_1608Metric; LCSC C2286
H1, H2: JLCToolingHole; AssemblyToolingHole
J1: Conn_01x05; PinSocket_1x05_P2.54mm_Horizontal_no_silk_fill
J2: Program; 1x04_P2.54mm_UPDI
J3: Conn_01x05; PinHeader_1x05_P2.54mm_Horizontal_no_pin_silk
J4, J5: Conn_01x04_MountingPin; JST_SH_SM04B-SRSS-TB_1x04-1MP_P1.00mm_Horizontal; LCSC C19270571
JP1: A2; SolderJumper-2_P1.3mm_Open_TrianglePad1.0x1.5mm_thermal_rel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
JP2: A1; SolderJumper-2_P1.3mm_Open_TrianglePad1.0x1.5mm_thermal_rel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
JP3: A0; SolderJumper-2_P1.3mm_Open_TrianglePad1.0x1.5mm_thermal_rel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
JP4: Vmot <-> Vio; SolderJumper-2_P1.3mm_Open_TrianglePad1.0x1.5mm_thermal_rel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
R1, R2, R3, R4, R5: 10k; R_0603_1608Metric; LCSC C25804
TP1: PA7; TestPoint_THTPad_D1.0mm_Drill0.5mm_small_valuesilk
TP2: RX; TestPoint_Pad_D1.5mm_ValueSilk
TP3: TX; TestPoint_Pad_D1.5mm_ValueSilk
TP4: PB4; TestPoint_THTPad_D1.0mm_Drill0.5mm_small_valuesilk
TP5: PB5; TestPoint_THTPad_D1.0mm_Drill0.5mm_small_valuesilk
TP6: PA3; TestPoint_THTPad_D1.0mm_Drill0.5mm_small_valuesilk
U1: ATtiny1616-M; VQFN-20-1EP_3x3mm_P0.4mm_EP1.7x1.7mm_with_step; LCSC C507118
U2: DRV8837; WSON-8-1EP_2x2mm_P0.5mm_EP0.9x1.6mm_solid_thermal; LCSC C191000

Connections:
/A0: JP3.1 (A), U1.17 (PC2)
/A1: JP2.1 (A), U1.16 (PC1)
/A2: JP1.1 (A), U1.15 (PC0)
/DBG_LED: D2.2 (A), U1.12 (PB2)
/MOTOR_A: A1.A, U2.3 (OUT2)
/MOTOR_B: A1.B, U2.2 (OUT1)
/M_1: U1.5 (PA4), U2.6 (IN1)
/M_2: U1.6 (PA5), U2.5 (IN2)
/M_SLEEP: U1.11 (PB3), U2.7 (~SLEEP)
/RX: TP2.1, U1.1 (PA2)
/R_FADER: A1.2, U1.7 (PA6)
/SCL: J1.5, J3.5, J4.4, J5.4, R4.2, U1.14 (PB0)
/SDA: J1.4, J3.4, J4.3, J5.3, R3.2, U1.13 (PB1)
/TOUCH: A1.T, U1.18 (PC3)
/TX: TP3.1, U1.20 (PA1)
/UPDI: J2.1, R5.2, U1.19 (~RESET/PA0)
/V_MOT: C3.1, C4.1, C5.1, J1.1, J3.1, JP4.2 (B), U2.1 (VM)
GND: A1.3, A1.MP, C1.2, C2.2, C3.2, C4.2, C5.2, J1.2, J2.4, J3.2, J4.1, J4.MP (MountPin), J5.1, J5.MP (MountPin), JP1.2 (B), JP2.2 (B), JP3.2 (B), R1.2, R2.2, U1.3 (GND), U1.21 (GND), U2.4 (GND), U2.9 (GND)
unnamed: D1.1 (K), R1.1
unnamed: D2.1 (K), R2.1
unnamed: TP6.1, U1.2 (PA3)
unnamed: TP1.1, U1.8 (PA7)
unnamed: TP4.1, U1.10 (PB4)
unnamed: TP5.1, U1.9 (PB5)
VCC: A1.1, C1.1, C2.1, D1.2 (A), J1.3, J2.3, J3.3, J4.2, J5.2, JP4.1 (A), R3.1, R4.1, R5.1, U1.4 (VCC), U2.8 (VCC)

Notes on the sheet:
(Tx/Rx alt pins)
Note: Must be ATtiny1616 or ATtiny3216 for 2 independent ADC peripherals, for simultaneous touch + potentiometer.

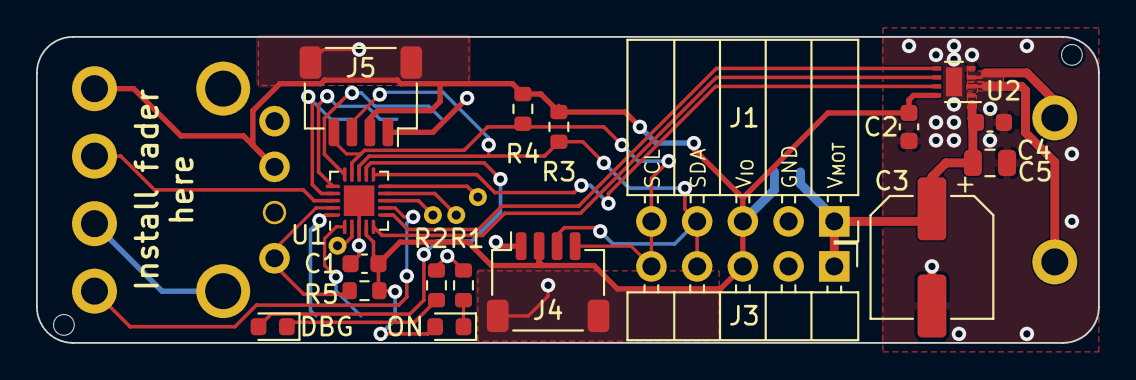
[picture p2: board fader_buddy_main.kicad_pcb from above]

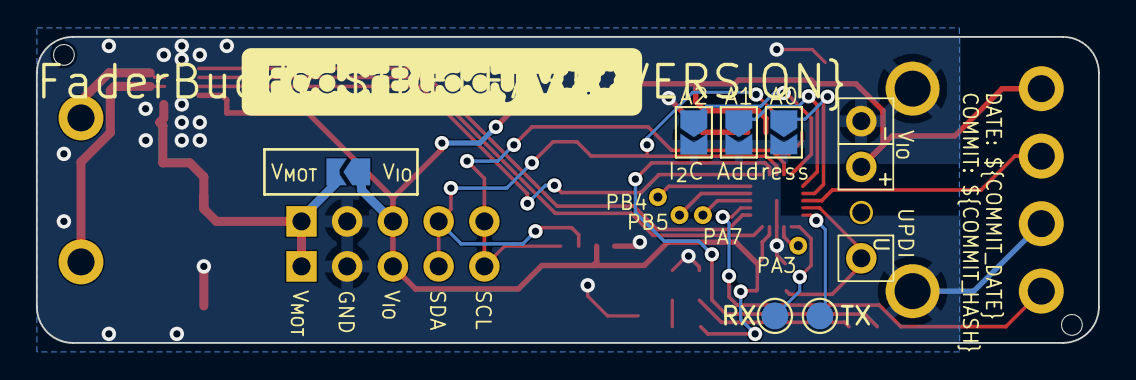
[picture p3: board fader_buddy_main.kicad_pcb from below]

Board: 2 copper layers, 59.0 x 17.0 mm, 32 parts (11 on the bottom side), 25 nets.

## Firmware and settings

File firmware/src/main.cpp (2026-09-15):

/*
 * Copyright 2026 Scott Bezek
 *
 * Licensed under the Apache License, Version 2.0 (the "License");
 * you may not use this file except in compliance with the License.
 * You may obtain a copy of the License at
 *     http://www.apache.org/licenses/LICENSE-2.0
 *
 * Unless required by applicable law or agreed to in writing, software
 * distributed under the License is distributed on an "AS IS" BASIS,
 * WITHOUT WARRANTIES OR CONDITIONS OF ANY KIND, either express or implied.
 * See the License for the specific language governing permissions and
 * limitations under the License.
 */

#include <Arduino.h>
#include <util/delay.h>
#include <Wire.h>
#include <ptc_touch.h>
#include <EEPROM.h>

#include "shared/i2c_data.h"
#include "shared/bootloader_protocol.h"
#include "util.h"
#include "motor_cal.h"
#include "motor_control.h"

// App metadata footer for the I2C bootloader host (see BL_APP_META_ADDR):
// the two bytes at the fixed end-of-flash address, always equal to the same
// FW_VERSION reported at runtime via REG_FW_VERSION below. Linked to that
// fixed address by -Wl,--section-start=.fw_meta=... in platformio.ini
// (env:fb_app_only); the bootloader does not read this.
extern "C" __attribute__((section(".fw_meta"), used))
const uint8_t FW_VERSION_FOOTER[2] = {
    (uint8_t)((FW_VERSION >> 8) & 0xFF),
    (uint8_t)(FW_VERSION & 0xFF),
};

#define PIN_LED (PIN_PB2)
#define LED_bm (1 << 2)  // PIN_LED on VPORTB, for direct port access

// Heartbeat blink period for PIN_LED, in ms (25% duty cycle). Overridable via
// build flag (-DDEBUG_LED_BLINK_PERIOD_MS=N) -- e.g. the fixed "old firmware"
// factory test image (see production_tools/programAndTest/factory_test_images/
// old_app_fw0.hex) is built with this halved so it's visually
// distinguishable from current firmware by blink rate alone.
#ifndef DEBUG_LED_BLINK_PERIOD_MS
#define DEBUG_LED_BLINK_PERIOD_MS (512)
#endif

#define PIN_MOTOR_nSLEEP (PIN_PB3)
#define MOTOR_nSLEEP_bm (1 << 3)  // PIN_MOTOR_nSLEEP on VPORTB, for direct port access

// Energizing pin A moves fader toward the motor end
#define PIN_MOTOR_A (PIN_PA4)
#define PIN_MOTOR_B (PIN_PA5)

// Value increases as fader approaches the motor end
#define PIN_FADER (PIN_PA6)

#define PIN_TOUCH (PIN_PC3)

#define PIN_ADDR_0 (PIN_PC2)
#define PIN_ADDR_1 (PIN_PC1)
#define PIN_ADDR_2 (PIN_PC0)

// PWM configuration
#if defined(MILLIS_USE_TIMERA0) || defined(__AVR_ATtinyxy2__)
  #error "This sketch takes over TCA0, don't use for millis here.  Pin mappings on 8-pin parts are different"
#endif

#define MOVEMENT_TIMEOUT_MILLIS (8000)
#define TOUCH_OVERRIDE_DURATION_THRESHOLD (50)
#define REMOTE_MOVEMENT_STEADY_THRESHOLD (300)
#define IDLE_DURATION_THRESHOLD (1000)

// Haptic parameters
#define HAPTIC_DEAD_ZONE (8)           // ADC units of dead zone around target
#define HAPTIC_BASE_PWM (150)           // Base PWM value for haptic force
#define HAPTIC_MAX_PWM (254)            // Maximum PWM value
#define HAPTIC_MAGNET_RANGE (60)        // Active range for magnetic endpoints (ADC units)
#define HAPTIC_BASE_MULTIPLIER (3.0f)   // Base force multiplier for haptics

// Tap detection timing
#define TAP_MAX_DURATION (200)            // Maximum tap press duration (ms)
#define DOUBLE_TAP_MAX_INTERVAL (200)     // Maximum time between taps (ms)
#define TAP_MAX_MOVEMENT (10)             // Maximum position change during tap (ADC units)

// Tap detection state machine
enum TapState : uint8_t {
  TAP_NONE = 0,                // No tap in progress
  TAP_FIRST_PRESSED,           // First tap touch detected
  TAP_WAITING_FOR_DOUBLE,      // Waiting to see if second tap occurs
  TAP_SECOND_PRESSED,          // Second tap touch detected
};

// Fixed-rate control tick, so gains and filter time constants keep the same
// meaning regardless of how long touch processing takes on a given loop().
#define CONTROL_TICK_US (500)           // 2 kHz (leaves loop headroom for touch)
#define VELOCITY_TAU_S (0.004f)         // velocity estimate smoothing, seconds

// Live gains - declared in motor_control.h, derived by motor_cal.cpp, defined
// here alongside the control law that consumes them. DEBUG_DRIVE builds let a
// host overwrite them at runtime via REG_DEBUG_GAINS.
float move_bd[2];
float move_inv_k[2];
float move_kv = MOVE_KV;
int16_t move_takeup_duty = MOVE_TAKEUP_DUTY;
float move_deadband = MOVE_DEADBAND;
float move_vel_min = MOVE_VEL_MIN;
#if DEBUG_DRIVE
// Runtime-tunable copies, so gain sweeps don't need a reflash per trial.
float move_vref_slope = MOVE_VREF_SLOPE;
float move_ramp_rate = MOVE_RAMP_RATE;
float move_takeup_ramp_rate = MOVE_TAKEUP_RAMP_RATE;
#else
#define move_vref_slope MOVE_VREF_SLOPE
#define move_ramp_rate MOVE_RAMP_RATE
#define move_takeup_ramp_rate MOVE_TAKEUP_RAMP_RATE
#endif

const float ALPHA = 0.05;
float input_ewma = 0;
float stiction_ramp = 0;                // extra drive ramped in while stalled
float move_max_velocity = MOVE_VEL_UNLIMITED;  // 0 = unlimited
float drive_ceiling = MOVE_MAX_DUTY;    // take-up ceiling, re-armed on direction change
int8_t move_direction = 0;              // commanded direction of the move in progress
float velocity_ewma = 0;                // ADC counts/sec, + toward the motor end
float last_control_ewma = 0;
uint32_t last_control_tick_us = 0;
uint32_t last_control_exec_us = 0;
uint32_t control_dt_us = CONTROL_TICK_US;  // measured interval of the current tick
#if DEBUG_DRIVE
uint16_t control_tick_period_us = CONTROL_TICK_US;  // runtime-tunable for sweeps
#else
#define control_tick_period_us CONTROL_TICK_US
#endif

// Touch state
cap_sensor_t touch_sensor;
uint16_t touch_recal_count = 0;  // Count of touch recalibrations since boot

// I2C slave base address (before A0/A1/A2 jumpers are applied)
const uint8_t I2C_BASE_ADDRESS = 0x20;

// EEPROM calibration storage. The magic changes whenever the layout does; an
// older record simply fails validation and the unit falls back to defaults
// until self-calibration is run again, which it needs anyway.
#define EEPROM_CALIBRATION_ADDR 0
#define EEPROM_CALIBRATION_MAGIC 0xCAF1  // Magic number to validate EEPROM data

struct CalibrationData {
  uint16_t magic;         // Magic number for validation
  uint16_t calib_min;     // Minimum ADC value (fader at one end)
  uint16_t calib_max;     // Maximum ADC value (fader at other end)
  MotorCalData motor;     // Per-unit motor characterisation (valid=0 if absent)
  uint16_t checksum;      // Simple checksum for data integrity
};

uint16_t input_calib_min = 40;
uint16_t input_calib_max = 1010;

int16_t target_adc = 512;
uint8_t current_register = REG_VERSION;  // Track which register was last accessed

// Haptic configuration storage
uint32_t haptic_config = 0;  // Bit-packed haptic configuration register (currently active layer's config)

// Layer state storage (27 bytes total) - Protocol v5+
uint16_t layer_haptic_configs[8];      // 16 bytes - 16-bit haptic config per layer
uint8_t layer_restore_positions[8];    // 8 bytes - restore position per layer (0-255)
uint8_t layer_speeds[8];               // 8 bytes - per-layer move speed (see LAYER_SPEED_*)
uint8_t active_layer = 0;              // 1 byte - currently active layer (0-7)
uint8_t pending_layer_change = 0xFF;   // 1 byte - deferred layer change (0xFF = none, 0-7 = layer)
uint8_t queried_layer = 0;             // 1 byte - for layer-addressed read protocol

const int16_t WINDOW_SIZE = 8;
int16_t position_window_upper = WINDOW_SIZE;
int16_t position_window_lower = 0;
int16_t position = 0;

uint32_t state = (Mode::MODE_INPUT_IDLE << STATE_MODE_bp);

// ============================================================================
// ISR <-> Main Loop Communication
// ============================================================================
// All variables used to pass data between ISR and main loop are prefixed with i2c_

// Main loop -> ISR communication (outgoing state for I2C reads)
volatile uint32_t i2c_outgoing_state = state;

// ISR -> Main loop communication (incoming requests from I2C writes)
volatile bool i2c_clear_error_request = false;
volatile bool i2c_self_cal_request = false;
volatile bool i2c_enter_bootloader_request = false;  // set when a valid REG_ENTER_BOOTLOADER arrives
volatile uint8_t i2c_layer_change_request = 0xFF;  // 0xFF = none, 0-7 = layer

struct LayerTargetWrite {
  uint8_t layer;
  uint8_t target;
  uint8_t speed;     // optional move speed (see LAYER_SPEED_*)
  bool has_speed;    // false = 3-byte write, leave the layer's speed as-is
  bool valid;
};
volatile LayerTargetWrite i2c_layer_target_write = {0, 0, LAYER_SPEED_FULL, false, false};

struct LayerHapticWrite {
  uint8_t layer;
  uint16_t config;
  bool valid;
};
volatile LayerHapticWrite i2c_layer_haptic_write = {0, 0, false};

#if DEBUG_DRIVE
// ---------------------------------------------------------------------------
// Open-loop drive register (system identification only; not built into the
// production firmware). Lets a host command a raw duty/decay/PWM-frequency
// combination so duty->velocity and friction breakaway can be measured
// directly instead of inferred from closed-loop behaviour.
// ---------------------------------------------------------------------------
#define DEBUG_DRIVE_WATCHDOG_MS (400)  // Auto-coast if the host stops refreshing
#define DEBUG_DRIVE_EDGE_MARGIN (30)   // ADC counts of endstop keep-out

volatile bool i2c_debug_gain_valid = false;
volatile uint8_t i2c_debug_gain_index = 0;
volatile int16_t i2c_debug_gain_value = 0;

volatile bool i2c_debug_drive_valid = false;
volatile uint8_t i2c_debug_drive_flags = 0;
volatile uint8_t i2c_debug_drive_duty = 0;

bool debug_drive_active = false;
int16_t debug_drive_value = 0;
bool debug_drive_slow_decay = false;
bool debug_drive_brake = false;
uint32_t debug_drive_last_update = 0;

// Snapshot of control-loop internals for REG_DEBUG_STATUS
float debug_status_velocity = 0;
float debug_status_error = 0;
uint16_t debug_status_loop_hz = 0;
uint16_t debug_status_tick_hz = 0;
uint16_t debug_loop_count = 0;
uint16_t debug_tick_count = 0;
uint32_t debug_rate_window_start = 0;
#endif

uint32_t remote_movement_start = 0;
uint32_t touch_state_change_millis = 0;
uint32_t remote_movement_steady_start = 0;
uint32_t input_last_change_millis = 0;
uint16_t remote_movement_start_position = 0;

// Tap detection state
TapState tap_state = TAP_NONE;
uint32_t tap_timestamp = 0;          // Timestamp of last tap-related event for duration/timeout tracking
uint16_t tap_position_start = 0;     // Raw ADC value when first touch started
uint8_t double_tap_nonce = 0;

bool pending_report_on_idle = false;

bool pending_calibrate_touch = false;
void calibrate_touch();
void reset_tap_detection();

// Forward declarations for layer management functions (Protocol v5+)
void request_layer_change(uint8_t new_layer);
void apply_layer_change(uint8_t new_layer);
void write_layer_target(uint8_t layer, uint8_t target);
void apply_move_speed(uint8_t speed);
void write_layer_haptic_config(uint8_t layer, uint16_t config);

Mode get_mode() {
  return static_cast<Mode>((state & STATE_MODE_bm) >> STATE_MODE_bp);
}

void set_mode(Mode mode) {
  state = (state & ~STATE_MODE_bm) | (mode << STATE_MODE_bp);

  if (mode != MODE_REMOTE_MOVEMENT_IN_PROGRESS) {
    // Any fresh movement starts without accumulated stiction ramp.
    stiction_ramp = 0;
  } else {
    // A commanded move is not local input, so drop any pending position-nonce
    // report - the host must not see the echo of its own command as a user move.
    pending_report_on_idle = false;
  }

  // Reset tap detection when entering modes where taps shouldn't be detected
  if (mode != MODE_INPUT_IDLE && mode != MODE_INPUT_ACTIVE) {
    reset_tap_detection();
  }
}

// ============================================================================
// Motor drive
// ============================================================================
// Declared in motor_control.h, which carries the bridge's truth table.
#define MOTOR_A_bm (1 << 4)
#define MOTOR_B_bm (1 << 5)

int16_t motor_drive_value = 0;  // Last applied signed drive, for status/LED

// Apply a signed motor drive.
//   drive > 0 pushes toward the motor end (rising ADC), < 0 toward the low end.
//   |drive| is 0..254, matching the TCA0 split-mode period.
//
// slow_decay selects how the off-portion of each PWM cycle is handled:
//   false (fast decay): PWM alternates drive <-> coast. Winding current decays
//     through the body diodes each cycle, so at high PWM frequency the average
//     current is far below what the duty implies and low-duty torque collapses.
//   true (slow decay): PWM alternates drive <-> brake, keeping current
//     circulating through the bridge. Average current (and torque) tracks duty
//     much more linearly, which is what lets us run an inaudible carrier
//     without losing low-speed authority.
void motor_set(int16_t drive, bool slow_decay, MotorIdle idle_mode) {
  if (drive > 254) drive = 254;
  if (drive < -254) drive = -254;
  motor_drive_value = drive;

  if (drive == 0) {
    // Set the static pin levels before releasing the pins from the timer, so
    // handover can't briefly present a drive combination.
    if (idle_mode == MOTOR_IDLE_BRAKE) {
      VPORTA.OUT |= (MOTOR_A_bm | MOTOR_B_bm);
    } else {
      VPORTA.OUT &= ~(MOTOR_A_bm | MOTOR_B_bm);
    }
    TCA0.SPLIT.CTRLB = 0;
    return;
  }

  uint8_t mag = (drive > 0) ? (uint8_t)drive : (uint8_t)(-drive);

  if (!slow_decay) {
    TCA0.SPLIT.HCMP1 = (drive > 0) ? mag : 0;
    TCA0.SPLIT.HCMP2 = (drive > 0) ? 0 : mag;
    TCA0.SPLIT.CTRLB = (TCA_SPLIT_HCMP1EN_bm | TCA_SPLIT_HCMP2EN_bm);
  } else {
    // Hold the leading pin high from PORT and PWM the trailing pin between
    // drive (low) and brake (high), so its high fraction is the inverse duty.
    if (drive > 0) {
      VPORTA.OUT |= MOTOR_A_bm;
      TCA0.SPLIT.HCMP2 = 254 - mag;
      TCA0.SPLIT.CTRLB = TCA_SPLIT_HCMP2EN_bm;
    } else {
      VPORTA.OUT |= MOTOR_B_bm;
      TCA0.SPLIT.HCMP1 = 254 - mag;
      TCA0.SPLIT.CTRLB = TCA_SPLIT_HCMP1EN_bm;
    }
  }
}

// At zero drive both the decay mode and the duty are irrelevant, so these two
// are the whole vocabulary of "stop": coast leaves the fader free to move,
// brake holds it against motion.
void motor_coast() { motor_set(0, false, MOTOR_IDLE_COAST); }
void motor_brake() { motor_set(0, false, MOTOR_IDLE_BRAKE); }

// Configure TCA0 for a single, permanently inaudible PWM carrier.
// Movement used to drop to DIV256 (306 Hz) because at 19.6 kHz with drive/coast
// PWM the motor needed ~190 duty to break away at all. Slow-decay drive (see
// motor_set) restores low-duty torque at the high carrier, so the audible
// carrier is no longer needed anywhere.
void setup_tca0() {
  // TakeOver TCA0 for PWM
  takeOverTCA0();

  // Enable split mode
  TCA0.SPLIT.CTRLD = TCA_SPLIT_SPLITM_bm;
  
  // Configure TCA0 for single-slope PWM
  // HCMPnEN bit: port output register for the corresponding WO[n+3] pin
  // PA4=WO4=HCMP1, PA5=WO5=HCMP2
  TCA0.SPLIT.CTRLB = (TCA_SPLIT_HCMP1EN_bm | TCA_SPLIT_HCMP2EN_bm);
  TCA0.SPLIT.HPER  = 254;
  TCA0.SPLIT.HCMP1 = 0;
  TCA0.SPLIT.HCMP2 = 0;

  TCA0.SPLIT.CTRLA = TCA_SPLIT_ENABLE_bm | TCA_SPLIT_CLKSEL_DIV4_gc;  // 19.6 kHz
}

// Big-endian multi-byte replies. Consolidating these into helpers rather than
// writing the bytes out at each call site is worth real flash on this part -
// every Wire.write() is a call, and the register handler has a lot of them.
void i2c_write_u16(uint16_t v) {
  uint8_t b[2] = {(uint8_t)(v >> 8), (uint8_t)v};
  Wire.write(b, 2);
}

void i2c_write_u32(uint32_t v) {
  uint8_t b[4] = {(uint8_t)(v >> 24), (uint8_t)(v >> 16), (uint8_t)(v >> 8), (uint8_t)v};
  Wire.write(b, 4);
}
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
void loop() {
  // Process any I2C requests that were queued by ISR callbacks
  process_i2c_requests();

  if (pending_calibrate_touch) {
    pending_calibrate_touch = false;
    motor_coast();
    delay(10);
    ptc_node_request_recal(&touch_sensor);
    // for (uint8_t i = 0; i < 4; i++) {
    //   digitalWrite(PIN_LED, HIGH);
    //   delay(100);
    //   digitalWrite(PIN_LED, LOW);
    //   delay(100);
    // }
  }
  // Keep the position filter fed from the free-running ADC on every pass, but
  // run the control law on a fixed tick so gains and filter constants have
  // real units instead of being per-loop-iteration.
  adc_drain();
#if DEBUG_DRIVE
  debug_loop_count++;
#endif

  uint32_t now_us = micros();
  if (now_us - last_control_tick_us >= control_tick_period_us) {
    // dt must be the interval since the previous *execution*, not since the
    // scheduled tick time: when the loop can't keep up, the schedule falls
    // behind real time and using it would skew the velocity estimate.
    control_dt_us = now_us - last_control_exec_us;
    last_control_exec_us = now_us;
    last_control_tick_us += control_tick_period_us;
    // If we fell far behind (e.g. a long blocking call), resynchronise rather
    // than running a burst of catch-up ticks.
    if (now_us - last_control_tick_us >= (uint32_t)control_tick_period_us * 4) {
      last_control_tick_us = now_us;
    }
    motor_update();

    // Copy state to i2c_outgoing_state atomically for ISR reads
    noInterrupts();
    i2c_outgoing_state = state;
    interrupts();
  }

  ptc_process(millis());

  // Straight to the port: digitalWrite() is ~180 bytes of pin lookup for a
  // heartbeat LED on a part with no flash to spare.
  if ((motor_drive_value != 0) ||
      (millis() % DEBUG_LED_BLINK_PERIOD_MS < DEBUG_LED_BLINK_PERIOD_MS / 4)) {
    VPORTB.OUT |= LED_bm;
  } else {
    VPORTB.OUT &= ~LED_bm;
  }

}

// callback that is called by ptc_process at different points to ease user interaction
void ptc_event_callback(const ptc_cb_event_t eventType, cap_sensor_t* node) {
  if (PTC_CB_EVENT_TOUCH_DETECT == eventType) {
    // MySerial.print("node touched:");
    // MySerial.println(ptc_get_node_id(node));

    // touch = true;
    touch_state_change_millis = millis();
    state |= STATE_TOUCH_bm;

    // Tap detection
    if (tap_state == TAP_NONE) {
      // First tap touch detected
      tap_timestamp = millis();
      tap_position_start = ADC1.RES;  // Store raw ADC value (no EWMA latency)
      tap_state = TAP_FIRST_PRESSED;
    } else if (tap_state == TAP_WAITING_FOR_DOUBLE) {
      uint32_t now = millis();
      if (now - tap_timestamp <= DOUBLE_TAP_MAX_INTERVAL &&
          tap_position_delta() <= TAP_MAX_MOVEMENT) {
        tap_timestamp = now;
        tap_state = TAP_SECOND_PRESSED;
      } else {
        // Too slow for double-tap, reset
        reset_tap_detection();
      }
    }
  } else if (PTC_CB_EVENT_TOUCH_RELEASE == eventType) {
    // MySerial.print("node released:");
    // MySerial.println(ptc_get_node_id(node));

    // touch = false;
    touch_state_change_millis = millis();
    state &= ~STATE_TOUCH_bm;

    // Tap detection: validate tap on release
    if (tap_state == TAP_FIRST_PRESSED || tap_state == TAP_SECOND_PRESSED) {
      uint32_t now = millis();
      uint32_t tap_duration = now - tap_timestamp;

      // Validate tap duration and movement
      if (tap_duration <= TAP_MAX_DURATION && tap_position_delta() <= TAP_MAX_MOVEMENT) {
        // Valid tap!
        if (tap_state == TAP_FIRST_PRESSED) {
          // First tap complete, wait for possible double-tap
          tap_timestamp = now;
          tap_state = TAP_WAITING_FOR_DOUBLE;
        } else if (tap_state == TAP_SECOND_PRESSED) {
          // Double-tap complete!

          // // Haptic kick for double-tap confirmation
          // TCA0.SPLIT.HCMP1 = 250;  // Motor direction A
          // TCA0.SPLIT.HCMP2 = 0;
          // delay(6);
          // TCA0.SPLIT.HCMP1 = 0;
          // TCA0.SPLIT.HCMP2 = 250;  // Motor direction B
          // delay(6);
          // TCA0.SPLIT.HCMP1 = 0;    // Stop
          // TCA0.SPLIT.HCMP2 = 0;

          increment_double_tap_nonce();
          reset_tap_detection();

          // Force state to idle after double-tap completion
          input_last_change_millis = now - IDLE_DURATION_THRESHOLD;
          set_mode(MODE_INPUT_IDLE);
        }
      } else {
        // Invalid tap (too long or too much movement)
        reset_tap_detection();
      }
    }
  } else if (PTC_CB_EVENT_CONV_SELF_CMPL == eventType) {
    // Do more complex things here
  } else if (PTC_CB_EVENT_CONV_CALIB & eventType) {
    // Increment recalibration counter on successful calibration
    if (eventType == PTC_CB_EVENT_CONV_CALIB) {
      touch_recal_count++;
    }
    // if (PTC_CB_EVENT_ERR_CALIB_LOW == eventType) {
    //   MySerial.print("Calib error, Cc too low.");
    // } else if (PTC_CB_EVENT_ERR_CALIB_HIGH == eventType) {
    //   MySerial.print("Calib error, Cc too high.");
    // } else if (PTC_CB_EVENT_ERR_CALIB_TO == eventType) {
    //   MySerial.print("Calib error, calculation timeout.");
    // } else {
    //   MySerial.print("Calib Successful.");
    // }
    // MySerial.print(" Node: ");
    // MySerial.println(ptc_get_node_id(node));
  }
}

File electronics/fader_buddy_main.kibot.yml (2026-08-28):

kibot:
  version: 1

global:
  # KiBot runs KiCad inside a container that can't see fonts installed on the
  # runner, so it installs any font found in <resources_dir>/fonts itself.
  # Without this, KiCad falls back to the stroke font for the Righteous
  # silkscreen text whenever it can't reuse the text's cached glyph outlines.
  resources_dir: ci/kibot_resources

preflight:
  check_zone_fills: true
  run_drc: true
  run_erc: true
  update_xml: true
  set_text_variables:
    - name: COMMIT_DATE_LONG
      command: 'python3 ci/util/rev_info.py git_date'
    - name: COMMIT_DATE
      command: 'python3 ci/util/rev_info.py git_date --short'
    - name: COMMIT_HASH
      command: 'python3 ci/util/rev_info.py git_short_rev'
    - name: RELEASE_VERSION
      command: 'python3 ci/util/rev_info.py git_release_version releases/electronics/'
  filters:
    - filter: 'Version text silkscreen overlap with knockout zone'
      error: 'silk_overlap'
      regex: 'PCB text.*on B\.Silkscreen'
  # filters:
  #   - filter: 'Lines crossing edge cuts'
  #     error: 'silk_over_copper'
  #     regex: 'Arc on Edge.Cuts'

outputs:
  - name: ibom
    comment: 'Interactive BOM'
    type: ibom
    options:
      dark_mode: true
      netlist_file: '%F.xml'
      extra_fields: 'LCSC,Mouser,Digikey,AliExpress,Note'

  - name: schematic
    type: pdf_sch_print

  - name: 'bom_csv'
    comment: "Bill of Materials in CSV format"
    type: bom
    options:
      use_alt: false
      number: 1

  - name: 3d
    type: render_3d
    options:
      view: 'top'
      copper: '#B39C00FF'
      board: '#E0D39CA1'
      solder_mask: '#0B0B0BD4'
      zoom: 7
      orthographic: true
      ray_tracing: true
      height: 512
      width: 1024

  - name: 3d_back
    type: render_3d
    extends: 3d
    options:
      view: 'bottom'

  - name: 3d_perspective
    type: render_3d
    extends: 3d
    options:
      output: '%f-3D_perspective%I%v.%x'
      view: 'top'
      zoom: 5
      rotate_z: -3
      rotate_x: 5
      orthographic: false
      height: 512
      width: 1024

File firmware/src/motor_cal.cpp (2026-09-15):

/*
 * Copyright 2026 Scott Bezek
 *
 * Licensed under the Apache License, Version 2.0 (the "License");
 * you may not use this file except in compliance with the License.
 * You may obtain a copy of the License at
 *     http://www.apache.org/licenses/LICENSE-2.0
 *
 * Unless required by applicable law or agreed to in writing, software
 * distributed under the License is distributed on an "AS IS" BASIS,
 * WITHOUT WARRANTIES OR CONDITIONS OF ANY KIND, either express or implied.
 * See the License for the specific language governing permissions and
 * limitations under the License.
 */

#include <Arduino.h>

#include "motor_cal.h"
#include "motor_control.h"

MotorCalData motor_cal = {0, {0, 0}, {0, 0}, {0, 0}};

// Three things are measured about this motor, per direction, and the MOVE_*
// gains in motor_control.h are re-derived from them (apply_motor_calibration):
//
//   breakaway  the duty at which the carriage first moves at all
//   k          ADC counts/sec of cruise gained per duty count above breakaway
//   v_jump     the speed motion starts at the instant breakaway is crossed
//
// See "Per-unit motor characterisation" in ABOUT_MOTOR_CONTROL.md for why a
// fixed set of gains can't serve every unit and how these are derived.

// Target open-loop gain for the velocity loop, k*KV, held constant across
// units by scaling KV with 1/k. 1.16 is what the reference unit ran at.
#define MOTORCAL_KV_LOOP_GAIN (1.16f)

// Bounds on the derived velocity floor (1.25x the Stribeck jump).
#define MOTORCAL_VEL_MIN_LO (200)
#define MOTORCAL_VEL_MIN_HI (1500)

// Time from the carriage reaching the deadband to actually stopping -
// reaction + detection + coast, not coast alone (see ABOUT_MOTOR_CONTROL.md).
#define MOTORCAL_STOP_TIME_MS (15)       // ms
#define MOTORCAL_TAKEUP_MARGIN (20)      // take-up ceiling sits this far above FF
// Bounds on the derived on-target window.
#define MOTORCAL_DEADBAND_LO (8)         // ADC counts
#define MOTORCAL_DEADBAND_HI (20)

// Measurement procedure: park, ramp to breakaway, then dwell at two duties
// above breakaway for a two-point fit of k. Runs alternate direction, so each
// one starts where the previous one left off.
#define MOTORCAL_PASSES (2)              // runs per direction, averaged
#define MOTORCAL_RAMP_RATE (80)          // duty/sec
// The ramp accumulates in fixed point at 1/256 duty per LSB, stepped per
// microsecond of tick as MOTORCAL_RAMP_STEP/4096. The 1/4096 is fine enough
// that a 500 us tick's increment doesn't truncate away most of itself.
#define MOTORCAL_RAMP_STEP \
  (((uint32_t)MOTORCAL_RAMP_RATE * 256 * 4096 + 500000UL) / 1000000UL)
#define MOTORCAL_RAMP_MAX (200)         // give up: this unit has no usable breakaway
#define MOTORCAL_MOTION_VEL (200)       // ADC counts/sec that counts as "moving"
#define MOTORCAL_JUMP_MS (40)            // window for capturing the Stribeck jump
#define MOTORCAL_DWELL_A (25)            // duty above breakaway, first fit point
#define MOTORCAL_DWELL_B (50)            // duty above breakaway, second fit point
#define MOTORCAL_DWELL_MS (100)          // hold per fit point
#define MOTORCAL_DWELL_AVG_MS (50)       // average over the last part of the hold
#define MOTORCAL_SETTLE_MS (200)         // coast to a stop before ramping
#define MOTORCAL_PARK_MARGIN (60)        // ADC counts from the end to start a run
#define MOTORCAL_PARK_DUTY (200)         // open-loop duty used to park
#define MOTORCAL_PARK_TIMEOUT (2500)     // ms
#define MOTORCAL_EDGE_MARGIN (25)        // abort if a run gets this close to an end

// Plausibility bounds - outside these, the measurement (not the fader) is
// wrong, so fall back to the compiled defaults.
#define MOTORCAL_BD_MIN (10)
#define MOTORCAL_BD_MAX (180)
#define MOTORCAL_K_MIN (8)
#define MOTORCAL_K_MAX (90)
#define MOTORCAL_VJUMP_MIN (100)
#define MOTORCAL_VJUMP_MAX (4000)

static uint32_t self_calibration_start = 0;
static uint8_t self_calibration_stage = 0;
#define SELF_CALIBRATION_TIMEOUT (1500)
#define SELF_CALIBRATION_BUFFER (0.995)  // Buffer factor to prevent hitting physical limits
static uint16_t self_calibration_adc_stage_0 = 0;
static uint16_t self_calibration_adc_stage_1 = 0;

// Self-calibration runs the endpoint sweep first, then characterises the motor
// (see the MOTORCAL_* constants). Stages 0-2 are the original endpoint sweep;
// their numbering is unchanged.
enum SelfCalStage : uint8_t {
  SELFCAL_ENDPOINT_LOW = 0,   // drive to the low end, record it
  SELFCAL_ENDPOINT_HIGH,      // drive to the high end, record it
  SELFCAL_ENDPOINT_APPLY,     // validate the span, adopt it in RAM
  SELFCAL_MOTOR_PARK,         // drive to the end this run starts from
  SELFCAL_MOTOR_SETTLE,       // coast to a genuine stop before measuring
  SELFCAL_MOTOR_RAMP,         // ramp to breakaway, then hold and capture the jump
  SELFCAL_MOTOR_DWELL_A,      // hold breakaway + A, measure cruise speed
  SELFCAL_MOTOR_DWELL_B,      // hold breakaway + B, measure cruise speed
  SELFCAL_MOTOR_NEXT,         // fold in the run, advance or finish
  SELFCAL_FINISH,             // derive gains, persist, return to the target
};

// Motor characterisation working state. Runs alternate direction starting with
// falling (the endpoint sweep leaves the carriage at the high end), so each run
// begins where the previous one ended.
static uint8_t motorcal_run = 0;          // 0..2*MOTORCAL_PASSES-1; even falling, odd rising
static bool motorcal_failed = false;
static uint16_t motorcal_duty = 0;        // ramped duty, fixed point (1/256 duty per LSB)
static int16_t motorcal_bd = 0;           // breakaway duty found by this run
static int16_t motorcal_vjump = 0;        // peak speed just after breakaway, ADC/s
static int16_t motorcal_dwell_a = 0;      // cruise speed at breakaway + A, ADC/s
static int32_t motorcal_vel_sum = 0;      // dwell velocity accumulator
static uint16_t motorcal_vel_n = 0;
// Per-direction accumulators, indexed [0] = falling, [1] = rising. Integer,
// because flash is the scarce resource on this part and a duty count or an
// ADC count/sec is all the resolution any of these needs.
static uint16_t motorcal_bd_sum[2] = {0, 0};
static uint16_t motorcal_k_sum[2] = {0, 0};
static uint16_t motorcal_vjump_max[2] = {0, 0};
static uint8_t motorcal_samples[2] = {0, 0};
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

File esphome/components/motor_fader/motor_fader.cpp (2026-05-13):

/*
 * Copyright 2026 Scott Bezek
 *
 * Licensed under the Apache License, Version 2.0 (the "License");
 * you may not use this file except in compliance with the License.
 * You may obtain a copy of the License at
 *     http://www.apache.org/licenses/LICENSE-2.0
 *
 * Unless required by applicable law or agreed to in writing, software
 * distributed under the License is distributed on an "AS IS" BASIS,
 * WITHOUT WARRANTIES OR CONDITIONS OF ANY KIND, either express or implied.
 * See the License for the specific language governing permissions and
 * limitations under the License.
 */

#include "motor_fader.h"

#include "esphome/core/application.h"
#include "esphome/core/log.h"

#include "i2c_data.h"

namespace esphome {
namespace motor_fader {

static const char *const TAG = "motor_fader";

MotorFader::MotorFader() : PollingComponent(), i2c::I2CDevice() {
  // Protocol v5: No layer state initialization needed - firmware manages layers
}

void MotorFader::setup() {
  ESP_LOGCONFIG(TAG, "Setting up motor_fader...");

  // Check protocol version
  uint8_t reg = REG_VERSION;
  auto write_result = this->write(&reg, 1, false);
  if (write_result != esphome::i2c::ErrorCode::NO_ERROR) {
    ESP_LOGE(TAG, "Init: failed to write register address for VERSION: %d", write_result);
    this->mark_failed();
    return;
  }

  uint8_t buffer = 0;
  auto read_result = this->read(&buffer, 1);
  if (read_result != esphome::i2c::ErrorCode::NO_ERROR) {
    ESP_LOGE(TAG, "Init: failed to read VERSION register: %d", read_result);
    this->mark_failed();
    return;
  }

  if (buffer != I2C_PROTOCOL_VERSION) {
    ESP_LOGE(TAG, "Init: Incompatible I2C protocol version. Expected %d but got %d", I2C_PROTOCOL_VERSION, buffer);
    this->mark_failed();
    return;
  }

  ESP_LOGCONFIG(TAG, "Motor Fader initialized (protocol v%d)", buffer);

  // Send initial haptic configurations to firmware
  for (uint8_t i = 0; i < 8; i++) {
    if (initial_haptic_configs_[i].valid) {
      ESP_LOGCONFIG(TAG, "Sending initial haptic config for layer %d: mode=%d, detents=%d, strength=%d",
                    i, initial_haptic_configs_[i].mode, initial_haptic_configs_[i].detent_count,
                    initial_haptic_configs_[i].detent_strength);
      send_layer_haptic_config_(i, initial_haptic_configs_[i].mode,
                                initial_haptic_configs_[i].detent_count,
                                initial_haptic_configs_[i].detent_strength);
    }
  }
  set_active_layer(0);
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

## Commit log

2025-01-27 Initial checkin of electronics
    [motor_fader_main.kibot.yml, motor_fader_main.kicad_pcb, motor_fader_main.kicad_sch]
2025-02-02 minor updates, mostly ready
    [motor_fader_main.kicad_pcb, motor_fader_main.kicad_sch]
2025-02-08 remove old kicad plot option
2025-02-08 Remove custom font to unbreak variable replacement in exports
    [motor_fader_main.kicad_pcb]
2025-02-08 Fix kibot release version filter
    [motor_fader_main.kibot.yml]
2025-02-08 Board cleanup, BOM cleanup
    [motor_fader_main.kicad_pcb, motor_fader_main.kicad_sch]
2025-05-15 WIP I2C
2025-05-15 PWM frequency
2025-05-26 Motor fader via ADC1 and working touch!
2025-05-26 Cleanup, i2c address pins
2025-05-28 i2c state data
2025-06-03 Updates - fix touch sticking, fix spurious input after movement, accept audible movement to avoid steady state error
    [main.cpp]
2025-06-06 Haptic magnetic ends experiment
2025-08-06 Add JST SH I2C connectors
    [motor_fader_main.kicad_pcb, motor_fader_main.kicad_sch]
2025-08-06 Add JLC part number for I2C connectors
    [motor_fader_main.kicad_sch]
2025-08-06 Exclude silkscreen clipping DRC
2025-08-07 3d model and update links in readme
    [motor_fader_main.kicad_pcb]
2025-08-07 JLC part numbers
    [motor_fader_main.kicad_sch]
2025-08-07 Move UPDI header
    [motor_fader_main.kicad_pcb]
2025-08-15 OMG update the MCU part number
    [motor_fader_main.kicad_sch]
2025-10-20 check in
    [motor_fader_main.kicad_pcb]
2025-10-26 Fix 32-bit state transfer, and add some test states to programAndTest
    [i2c_data.h, main.cpp]
2025-10-26 Fix self-calibration, add self-calibration to programAndTest
    [main.cpp]
2026-01-11 fix esphome enum and init layer 0
    [motorFaderESPHomeComponent.cpp]
2026-01-12 debugging state issues and double tap issues
    [i2c_data.h, main.cpp, motorFaderESPHomeComponent.cpp]
2026-01-12 fix state bit bug, clean up layer changes
    [i2c_data.h, main.cpp, motorFaderESPHomeComponent.cpp]
2026-01-16 Fix layer change issues
    [main.cpp]
2026-03-06 Add demo gif to README
    Added a demo image for the motorFader project.
2026-05-13 Add UPDI connection diagram
    Updated wiring diagram and added image link for UPDI Friend.
2026-05-13 doc updates; export rasterized schematic
2026-05-13 Simplify README Getting Started and Wiring sections (#3)
    Replace bulky What You'll Need tables with a concise Getting Started bullet
    list, referencing ABOUT_PCB_FABRICATION.md and ABOUT_UPDATING_FIRMWARE.md for
    details. Combine the two STEMMA QT wiring subsections into one, showing direct
    pin-header chaining first then STEMMA QT chaining as an alternative.
2026-05-14 revert unintentional change to electronics/motor_fader_main.kicad_pro
2026-05-14 Rename to FaderBuddy part 4 - electronics updates and other ref updates
    [fader_buddy_main.kicad_pcb, fader_buddy_main.kicad_sch]
2026-05-19 Update electronics to kicad 10 (#4)
    [fader_buddy_main.kicad_pcb, fader_buddy_main.kicad_sch]
2026-07-12 Fix ESPHome 2026.3+ I2C compatibility (#5)
    Use write_read() for register reads; the three-argument
    write(data, len, stop) overload was removed in ESPHome 2026.3.0.
    [fader_buddy.cpp]
2026-08-11 Expose FaderBuddy chip serial number as a text sensor (#7)
    Read the 10-byte REG_SERIAL factory ID once at setup and cache it as an
    uppercase hex string (matching the production jig / WebHID convention).
    Add a fader_buddy text_sensor platform with a serial_number key, expose
    get_serial_number() for lambdas, and log the serial in dump_config().
2026-08-27 Tidy ESPHome docs a bit
    Props to AcidWizard in discord for the suggestion to move the example above the raw field docs.
2026-08-27 Generate panelized PCBs (#9)
    Use kikit panelization and update CI to generate panelized artifacts
    [fader_buddy_main.kicad_pcb]
2026-08-28 [electronics] Fix panelized renders (#10)
    - Fix missing font on panelized render
    - Fix missing 3d model lib on panelized render
    [fader_buddy_main.kibot.yml]
2026-09-13 Rewrite motor control, add remote movement speed control (#11)
    Gave Claude a program&test jig and asked it to redo the motor control to
    reduce overshoot and eliminate audible noise (since I previously lowered
    the PWM freq as a cheap way to get better torque). Claude ran a bunch of
    tests to characterize the fader's performance and then wrote a new
    control loop that seems to work pretty well. Also made a bunch of
    quality of life tweaks.
    Big changes:
    - quiet movement
    - less overshoot, and built-in motor self calibration
    - adjustable movement speed
    - firmware version reporting
    - esphome improvements:
    - automatically register/report serial number and firmware version text
    fields per fader
    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
    [fader_buddy.cpp, i2c_data.h, lab_main.cpp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]
2026-09-14 I2C bootloader for ESPHome-driven firmware updates (#6)
    ## Summary
    Adds a bootloader to the fader firmware so a fader can be updated over
    I2C. Updating a fader no longer needs a UPDI programmer, and an ESP32
    host can update every fader on the bus.
    NOTE: FaderBuddy boards running older firmware will not be able to
    utilize the ESPHome update mechanism until they've been fully re-flashed
    (via UPDI) with the new bootloader firmware added in this PR.
    ## Fader firmware
    - A new bootloader occupying the first 0x600 bytes of flash. It erases
    and writes the application section over I2C, checks a CRC on every page,
    and verifies the whole image before starting the app.
    - A new register, `REG_ENTER_B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
    [bootloader.c, fader_buddy.cpp]
2026-09-14 Fix bootloader address, i2c probe backoff
    [bootloader.c, fader_buddy.cpp]
2026-10-16 Add reference 60mm motor fader 3d design
2026-11-11 Export a STEP model of the board from electronics CI (#20)
    Adds a KiBot `step` output to `electronics/fader_buddy_main.kibot.yml`,
    so CI produces `fader_buddy_main.step` (a 3D model of the assembled
    board, in metric units) for mechanical CAD.
    It goes into `electronics/build/outputs` with the other KiBot outputs,
    so the existing steps already archive it as the `electronics` workflow
    artifact and sync it to S3
    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
